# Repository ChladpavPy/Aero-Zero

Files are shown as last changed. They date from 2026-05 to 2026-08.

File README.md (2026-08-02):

# Aero-Zero Custom Flight Controller

I started this project, because I wanted to build fully autonomous ai drone. When I looked at the flight controllers available on the market, they were full of hardware that I just do not need or just that I could not add things that I want (for example the Rasberry pi zero 2w) . Most boards also waste a lot of space on powering analog OSD chips, which is completely useless for me because I am flying a purely digital HD system like Walksnail Avatar. Because the technology changed and digital is the standard now, I realized it is just a waste of space to keep the analog stuff and massive connectors.

I am using Raspberry Pi Zero 2W as the computer. Firstly I wanted to use something more powerful to be able to run ai smoother, like allwinner cubie a7z, but it is more expensive and the biggest issue is the firmware and gpio programming on this device. I have no idea, how I would programm this device, when there are basically no manuals or datasheets to this, so I am using the basic raspberry pi zero 2w. So the most interesting thing on this pcb is the pi zero 2w, which is connected to the board by set of pins and screw holes that can be mounted on the pcb by screws.

The drone itself would be able to lift off and fly to a location based on the gps, there is the barometer, from which the drone gets the current altitude and can get to ground. I am using walksnail camera and elrs, plus LIDAR. There is a jst connector for led strip, while at the same time there are built in leds on the drone chassis, esc unit connector and built in electromagnetic buzzer and boot and rst buttons.

The first stage was actually studying the STM32 pinouts and figuring out as much possible of how modern flight controllers handle gyro SPI communication and high speed SDIO routing.

A custom mainboard designed to replace standard generic flight controllers. Built to handle Betaflight high speed kinematics and communicate directly with a Raspberry Pi Zero 2W. Designed entirely from scratch in KiCad 10.

## Project Features

* **Microcontroller:** STM32F405 (100-pin, 32-bit ARM Cortex-M4)
* **Stackup:** 4-Layer PCB (Signal / GND / GND+Power / Signal) for internal routing and better EMI shielding against switching inductors
* **IMU (Gyro):** TDK InvenSense ICM-42688-P connected via dedicated hardware SPI1 bus for high-speed kinematics
* **Barometer:** Goertek SPL06-007 on-board sensor for accurate altitude telemetry
* **Power:** VBAT main input with robust 5V switching regulator (TPS54302) and isolated 3.3V sensor rails
* **Connectivity:** USB-C for main communication with USBLC6 ESD protection, native Raspberry Pi UART interface
* **Digital Video:** Dedicated Walksnail/Caddx VTX JST-SH port (Analog OSD intentionally removed to save space)
* **Storage:** Integrated MicroSD slot (Hirose Push-Pull) routed via high-speed 4-bit SDIO bus for blackbox logging
* **Hardware Protections:** Strict 1:1 hardware pin layout for GPS and LiDAR connectors to prevent accidental voltage shorts during assembly
* **Radio Link:** Dedicated UART port for 2.4GHz ExpressLRS nano receiver.

## Firmware

Since this board is built around a custom STM32F405 microcontroller, it runs on the open-source [Betaflight](https://github.com/betaflight/betaflight) firmware. Instead of writing custom flight control loops from scratch, the firmware setup uses a custom target configuration. You can find the complete pin-mapping and resource file (`AeroZero_BF_Config.txt`) ready in the `Firmware` folder.

## Gallery

### 3D PCB Render
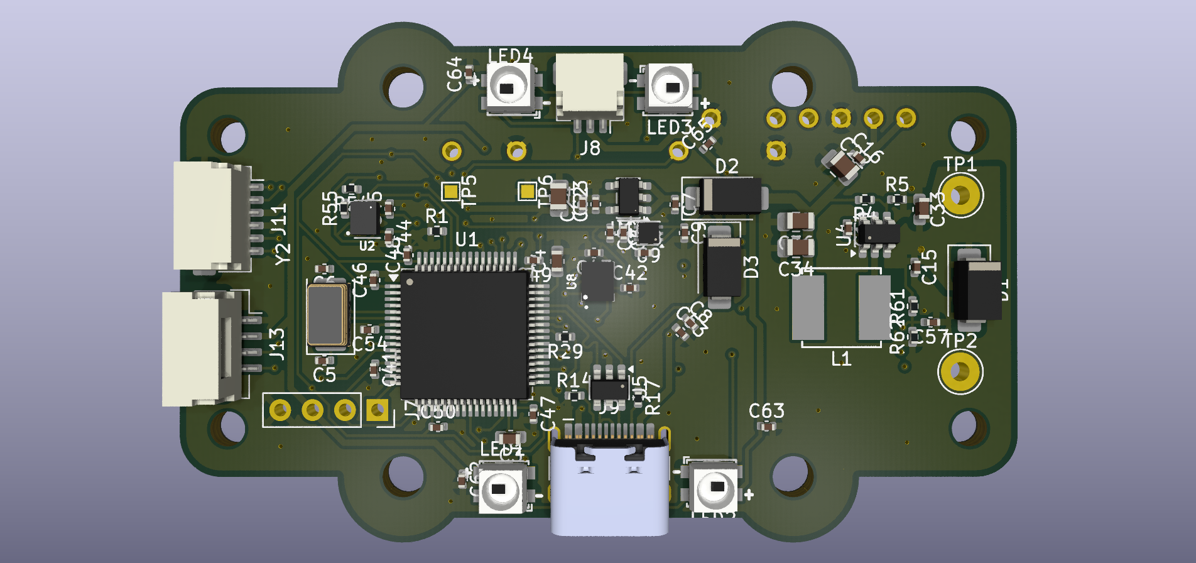
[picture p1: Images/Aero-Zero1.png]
PCB 3D Top


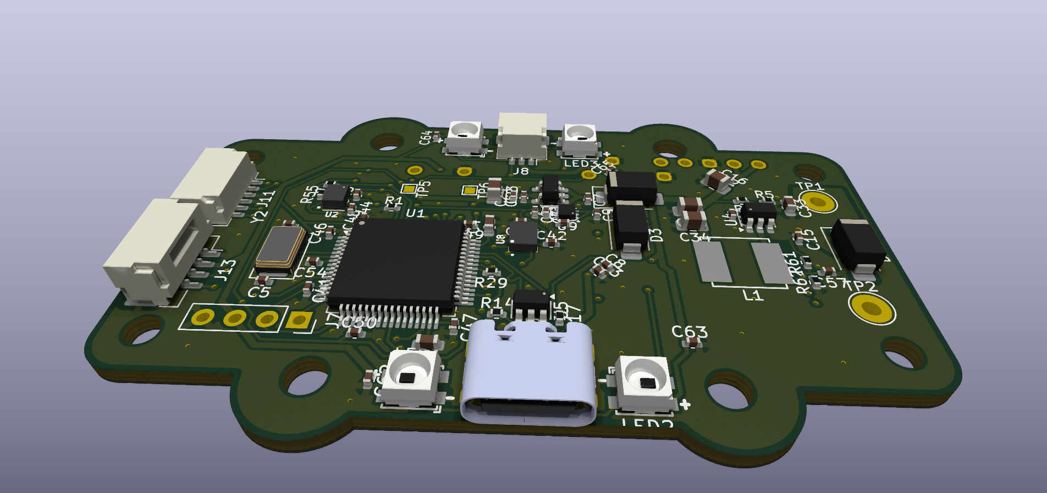
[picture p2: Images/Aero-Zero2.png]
PCB 3D Angle


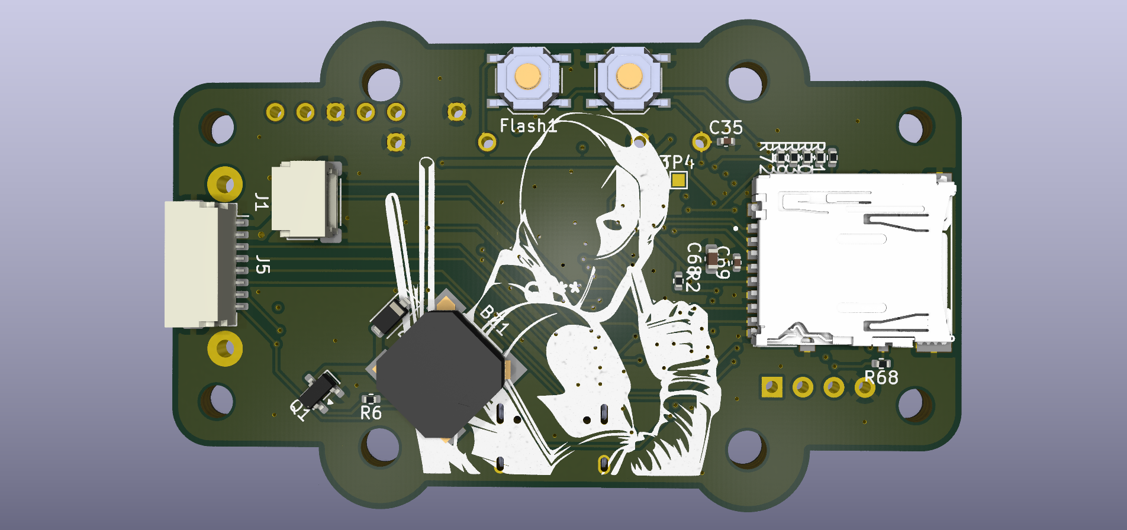
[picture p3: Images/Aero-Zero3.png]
PCB 3D Bottom


### PCB 

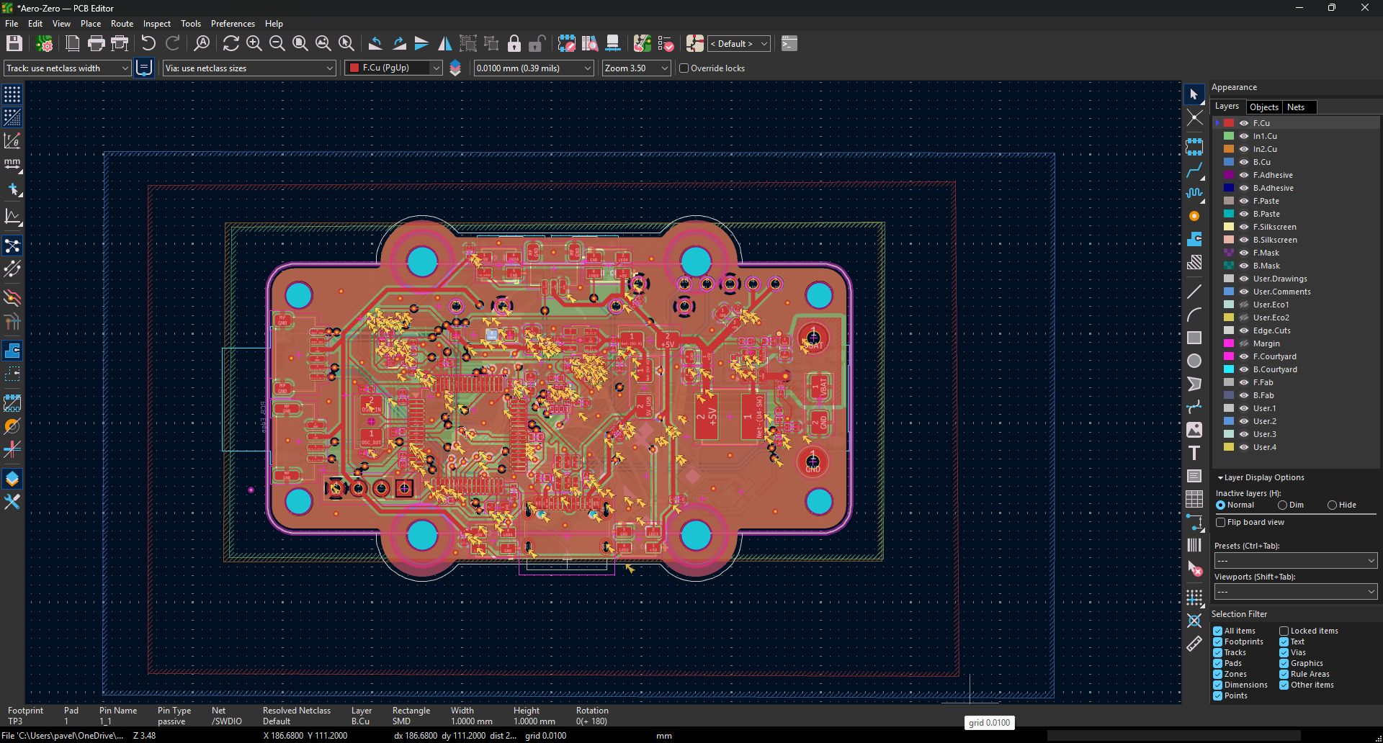
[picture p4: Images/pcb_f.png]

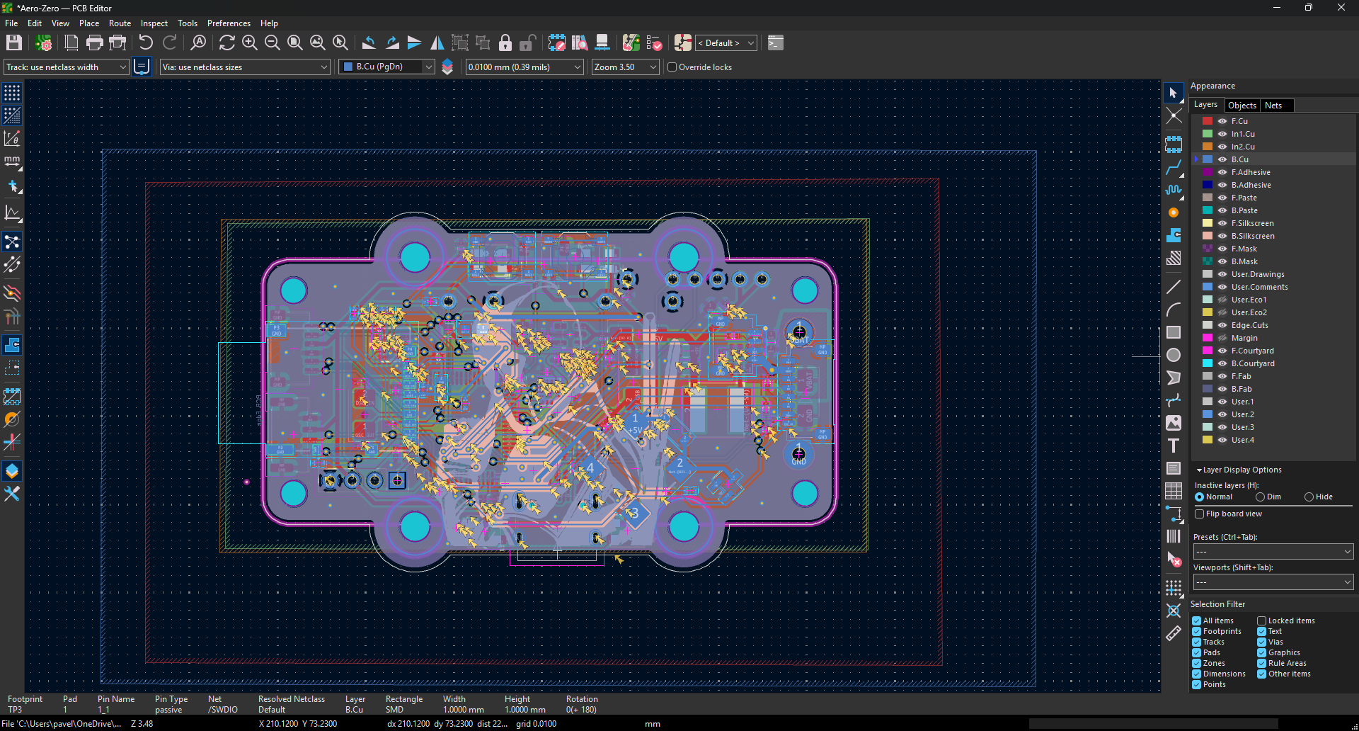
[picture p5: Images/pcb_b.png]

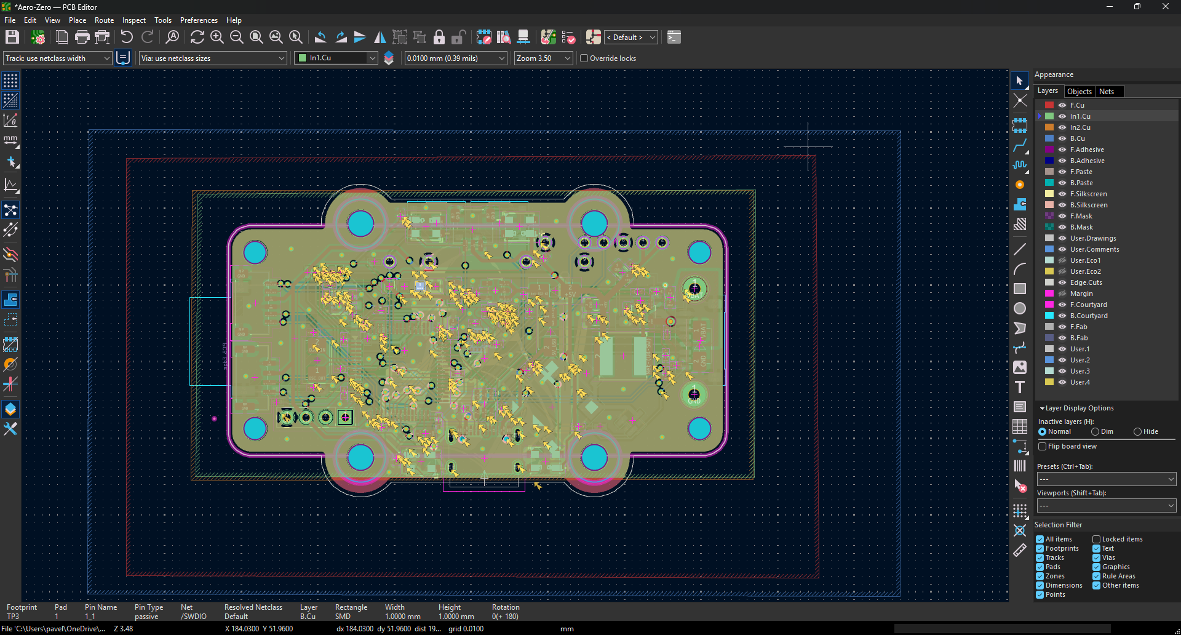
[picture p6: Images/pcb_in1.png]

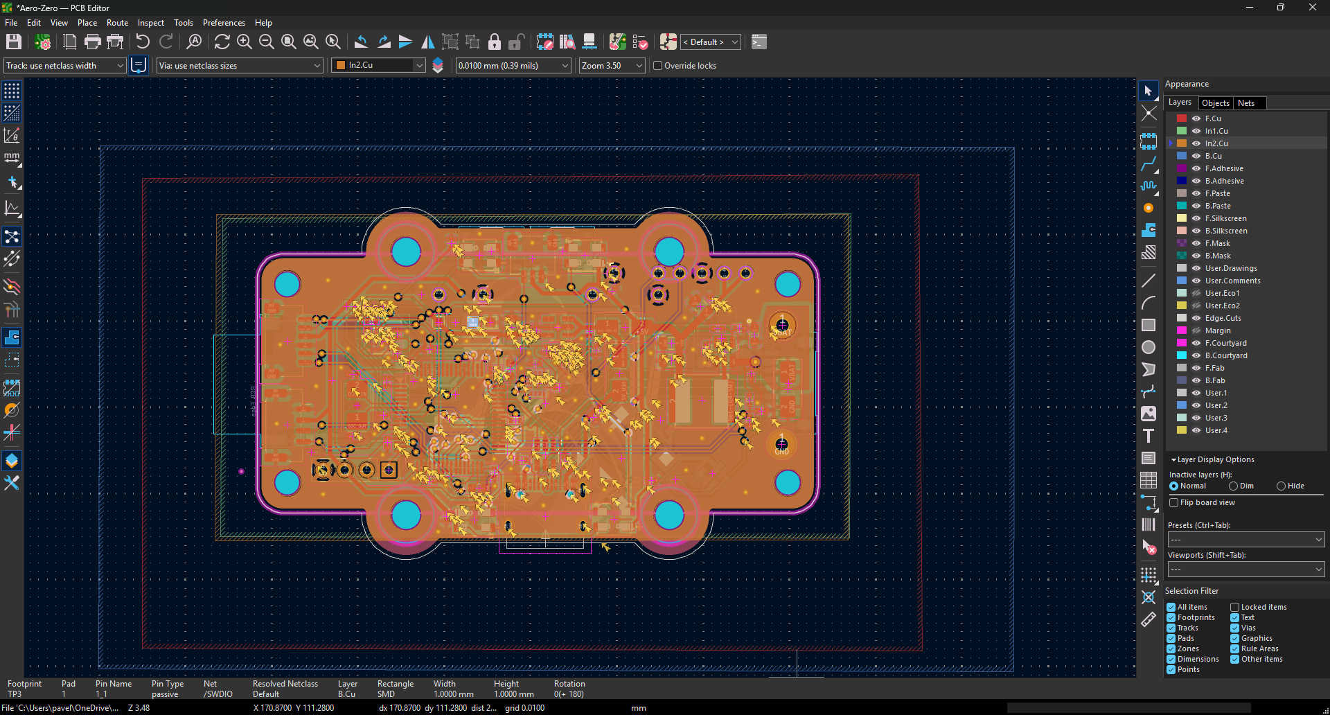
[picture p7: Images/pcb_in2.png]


### Schematics

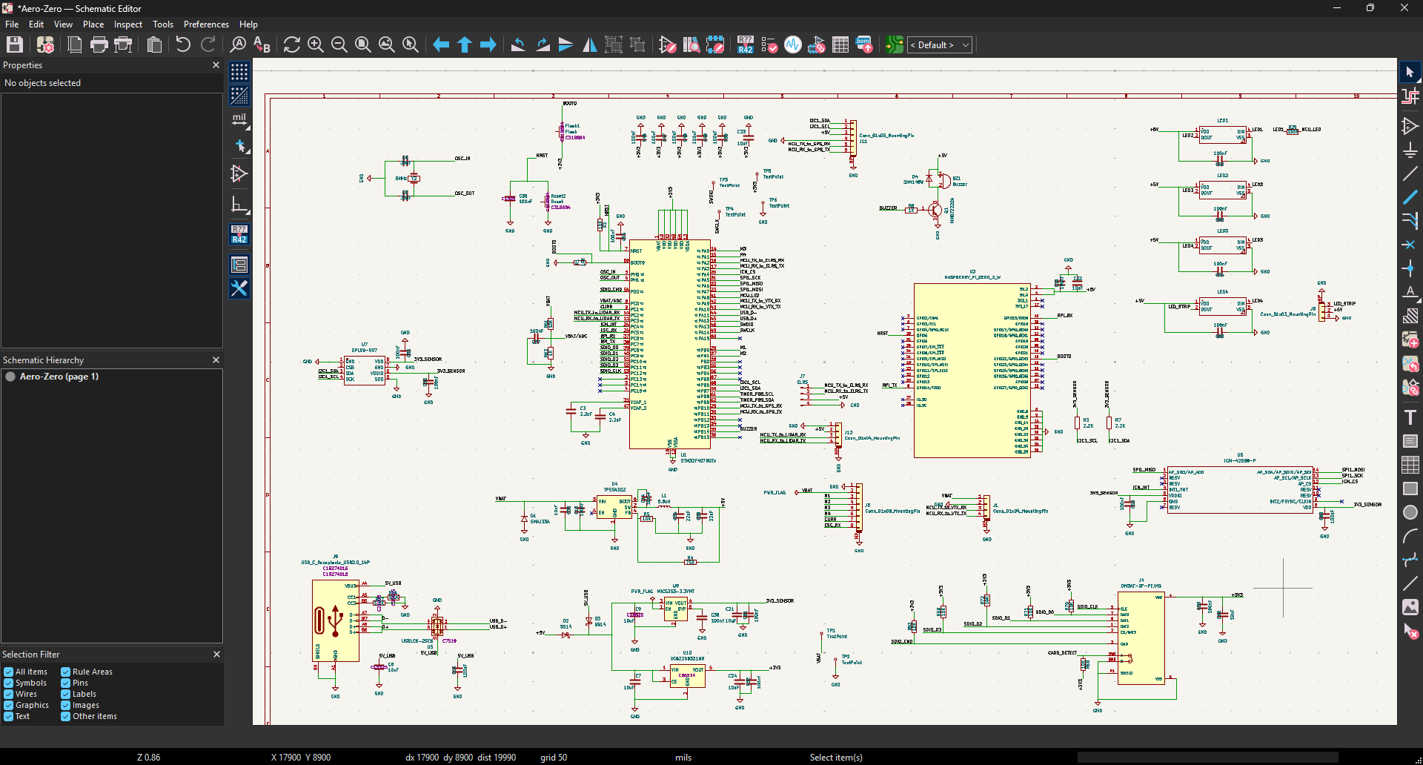
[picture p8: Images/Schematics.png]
SCHEMATICS


### Mechanical Integration MARK4
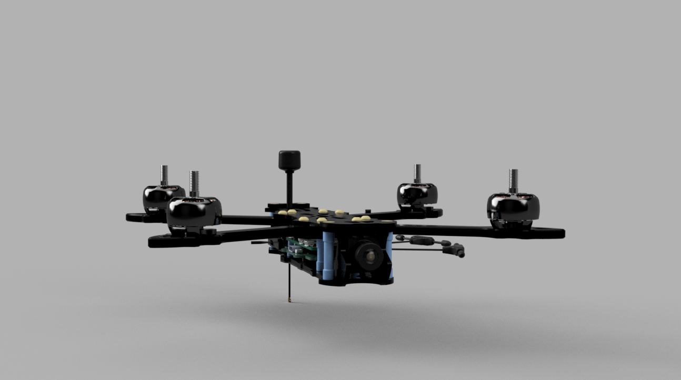
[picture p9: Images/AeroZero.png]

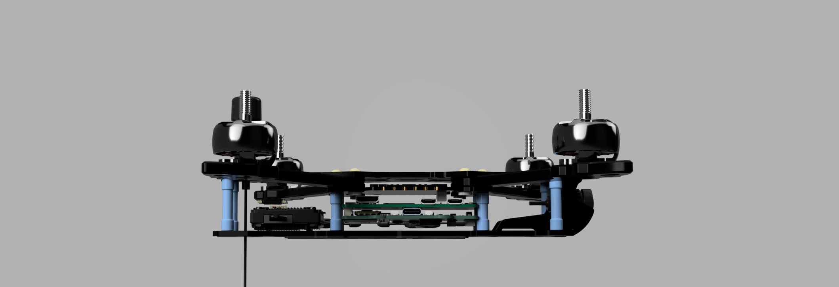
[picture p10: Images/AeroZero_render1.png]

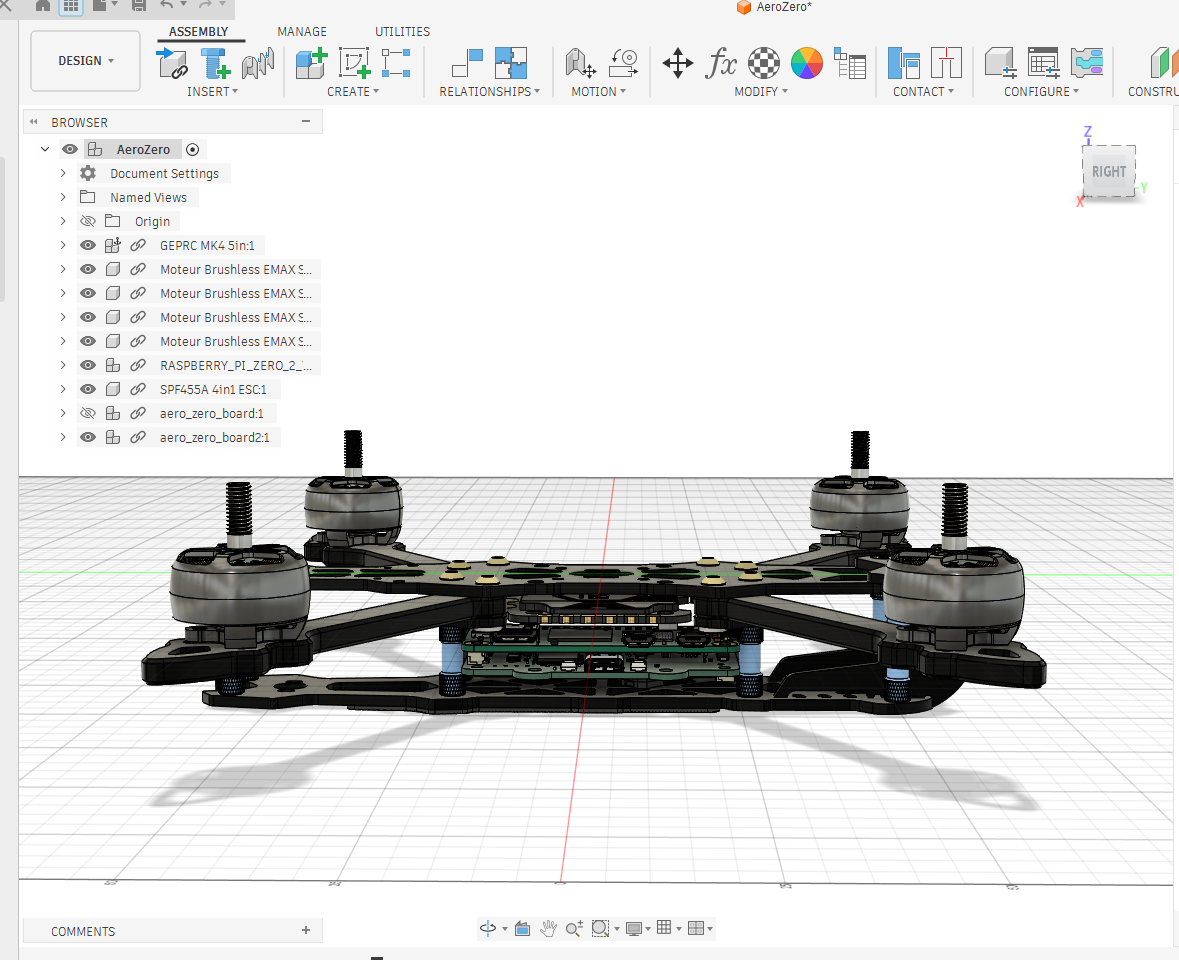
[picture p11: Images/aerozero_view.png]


### Mechanical Integration CUSTOM AERO-ZERO CAD
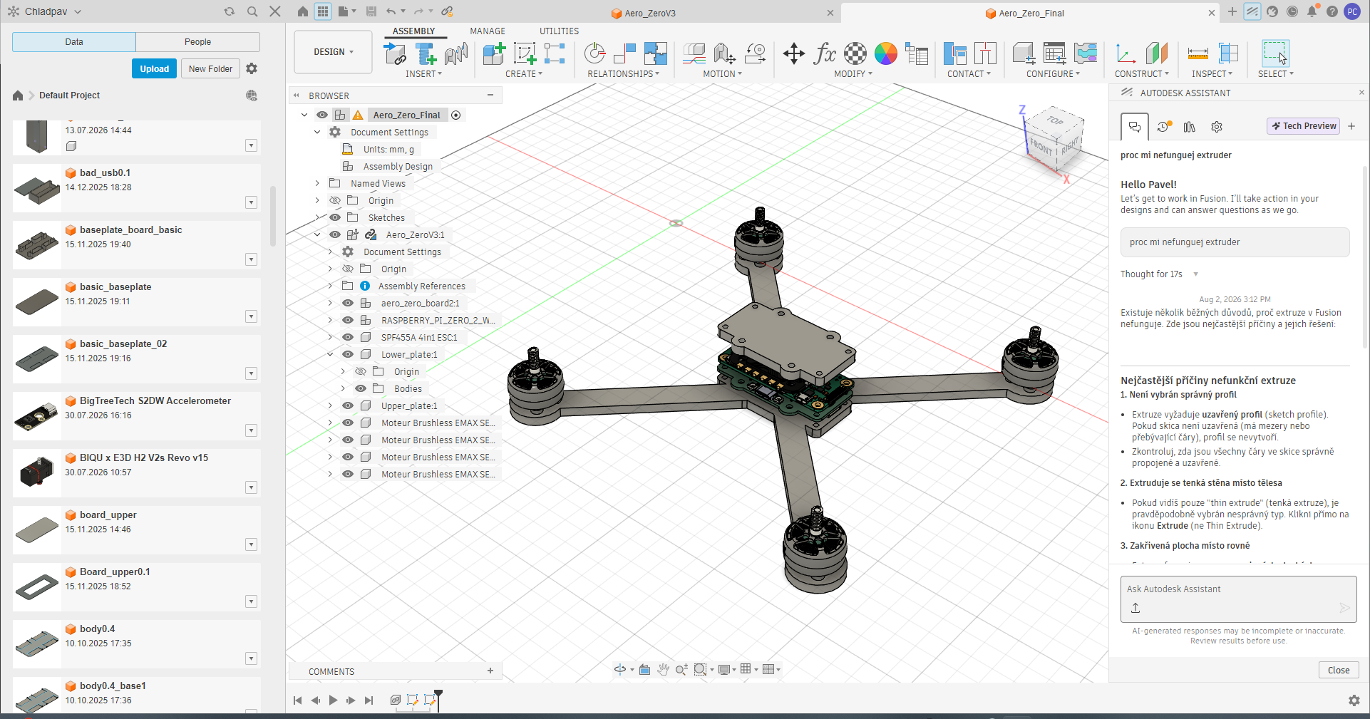
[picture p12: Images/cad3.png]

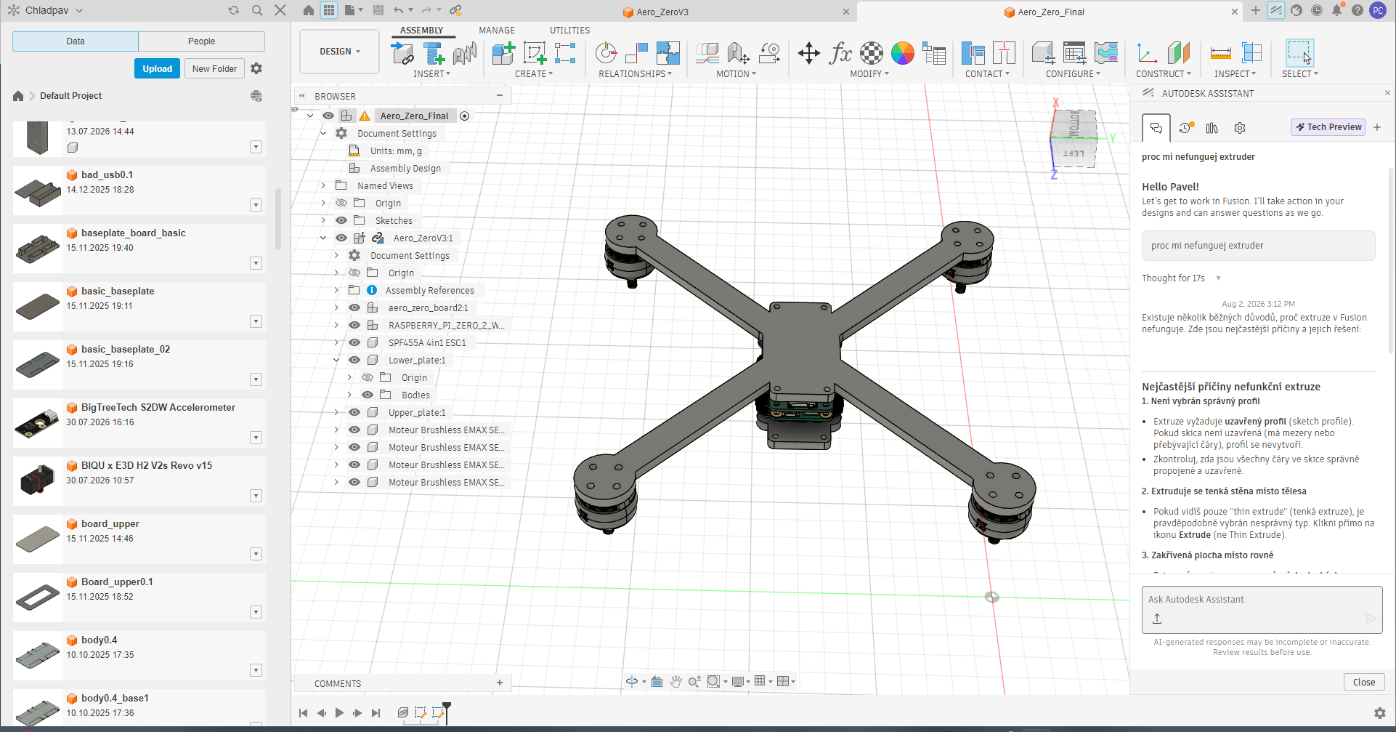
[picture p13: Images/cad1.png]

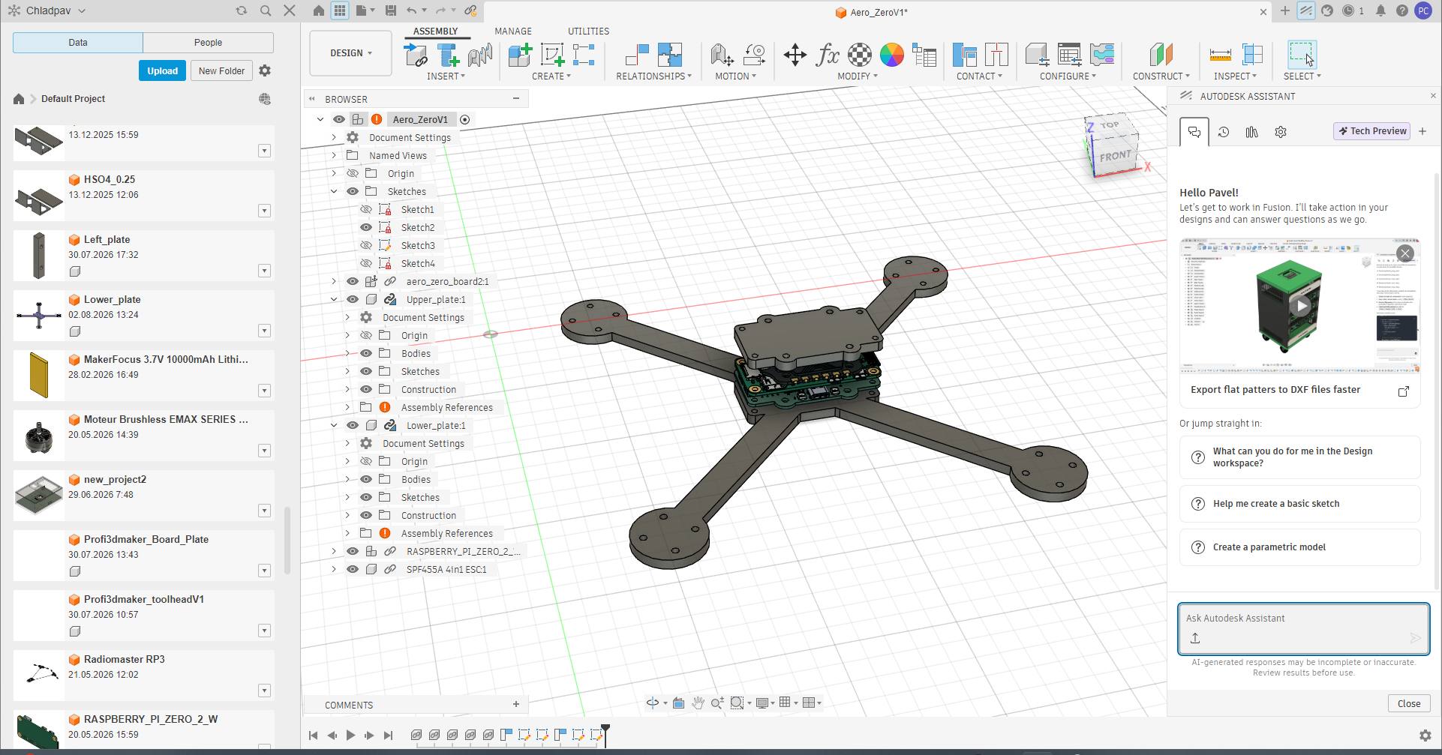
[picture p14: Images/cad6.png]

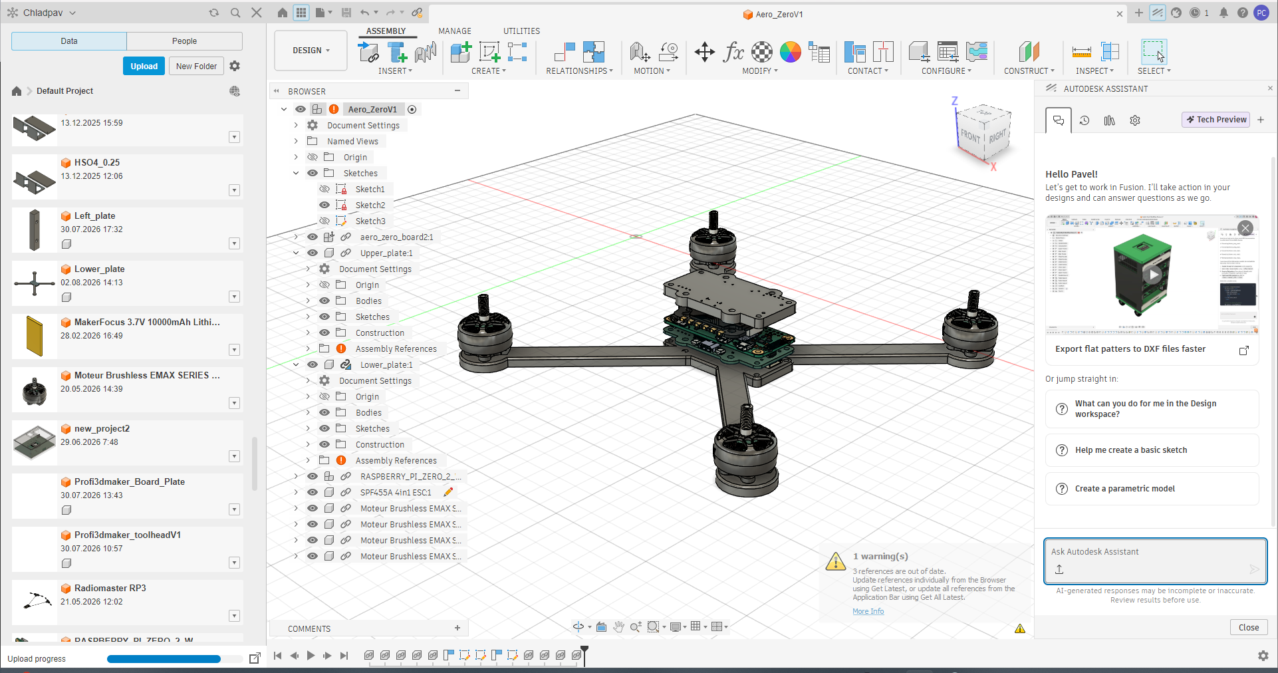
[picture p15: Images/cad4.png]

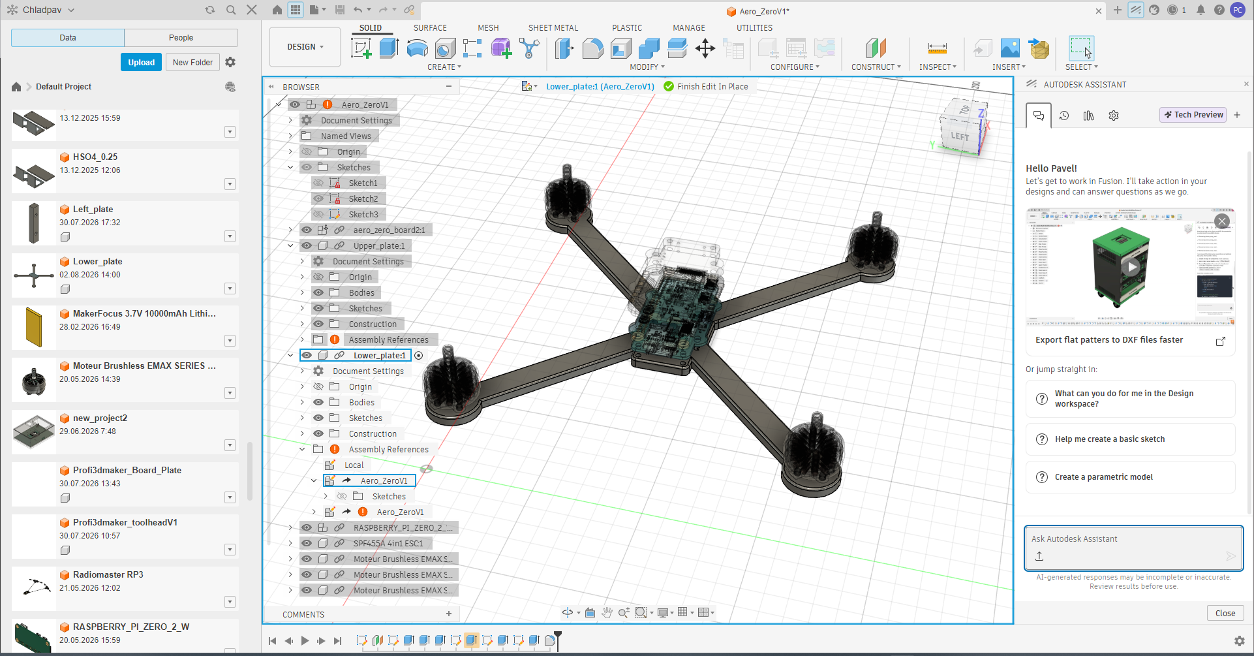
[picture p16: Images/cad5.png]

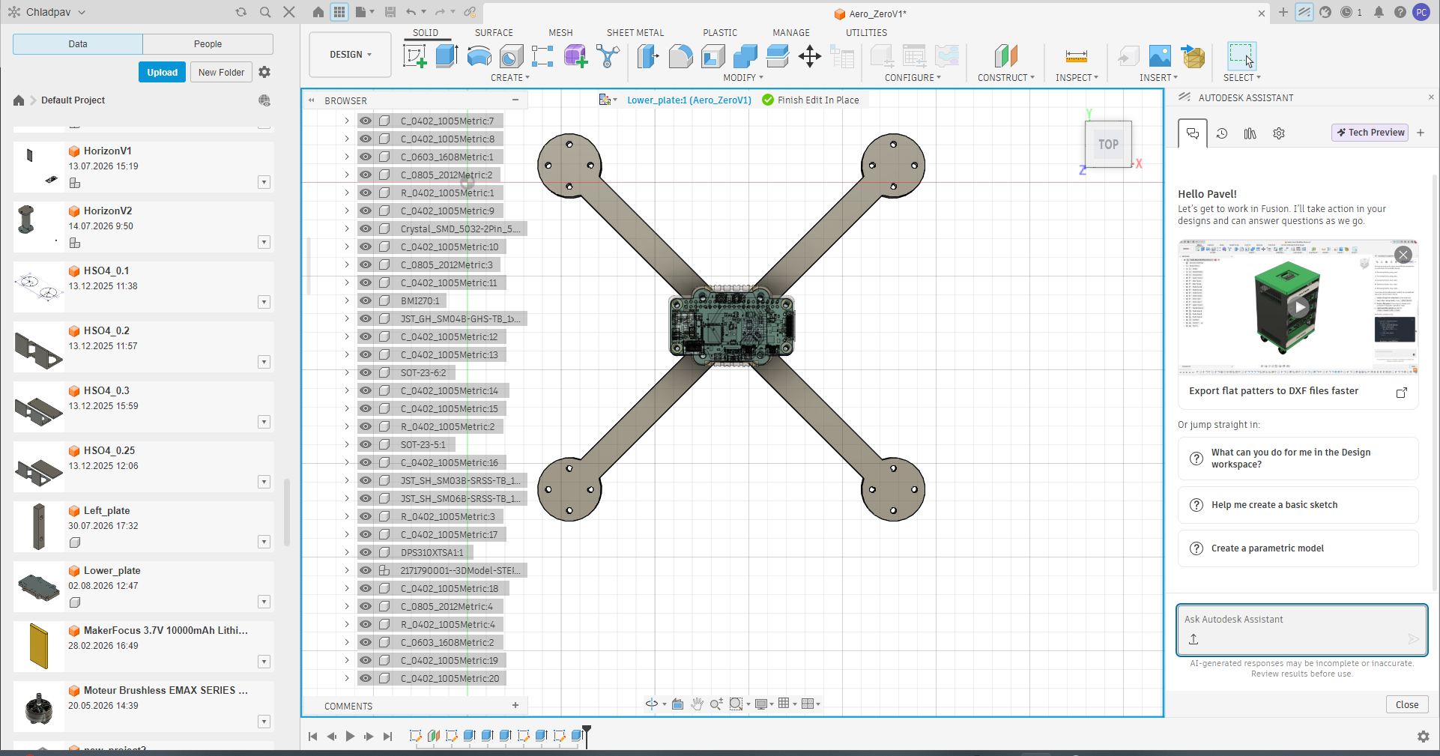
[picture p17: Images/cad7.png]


---

## Bill of Materials (BOM)

| Component | Qty | Purpose / Description | Price (USD) | Link / Distributor |
| :--- | :---: | :--- | :--- | :--- |
| **Custom PCBA (Aero-Zero)** | 2 | Custom designed 4-layer STM32 flight controller board. Fully assembled via JLCPCB SMT. | $131.50 | JLCPCB |
| **GEPRC GEP-M1025-DQ GPS** | 1 | High-precision positioning data (u-blox M10) with integrated QMC5883L compass and backup DPS310 barometer. | $19.80 | [Banggood](https://www.banggood.com/cs/GEPRC-GEP-M1025-Series-M10-Chip-GPS-Module-for-RC-Drone-FPV-Racing-Helicopter-Quadcopter-RC-Airplane-Car-p-2000868.html?ID=6324596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) |
| **SpeedyBee BLS 60A 30x30 4-in-1 ESC** | 1 | Electronic Speed Controller (4-in-1) for driving the primary flight motors | $44.00 | [AliExpress](https://www.aliexpress.com/item/1005010400734832.html) |
| **EMAX ECO II 2207 1700KV Brushless Motor** | 4 | Primary propulsion system providing lift and flight dynamics for the drone chassis | $59.00 | [AliExpress](https://www.aliexpress.com/item/1005001706267138.html) |
| **Raspberry Pi Zero 2 W** | 1 | Secondary AI and computer vision processing unit for autonomous flight capabilities | $20.17 | [RPiShop (Czech Republic)](https://rpishop.cz/raspberry-pi-zero/4311-raspberry-pi-zero-2-w.html) |
| **BETAFPV Nano 2.4GHz ELRS** | 1 | 2.4GHz ExpressLRS receiver with T-Type antenna for reliable, low-latency radio control link. | $9.07 | [Aliexpress](https://a.aliexpress.com/_EHLASWw) |
| **LCSC Discrete Components** | 1 | Bottom-side passive components (SD slot, buzzer, flyback diode, resistors/capacitors) for manual assembly. | $16.21 | lcsc.com |

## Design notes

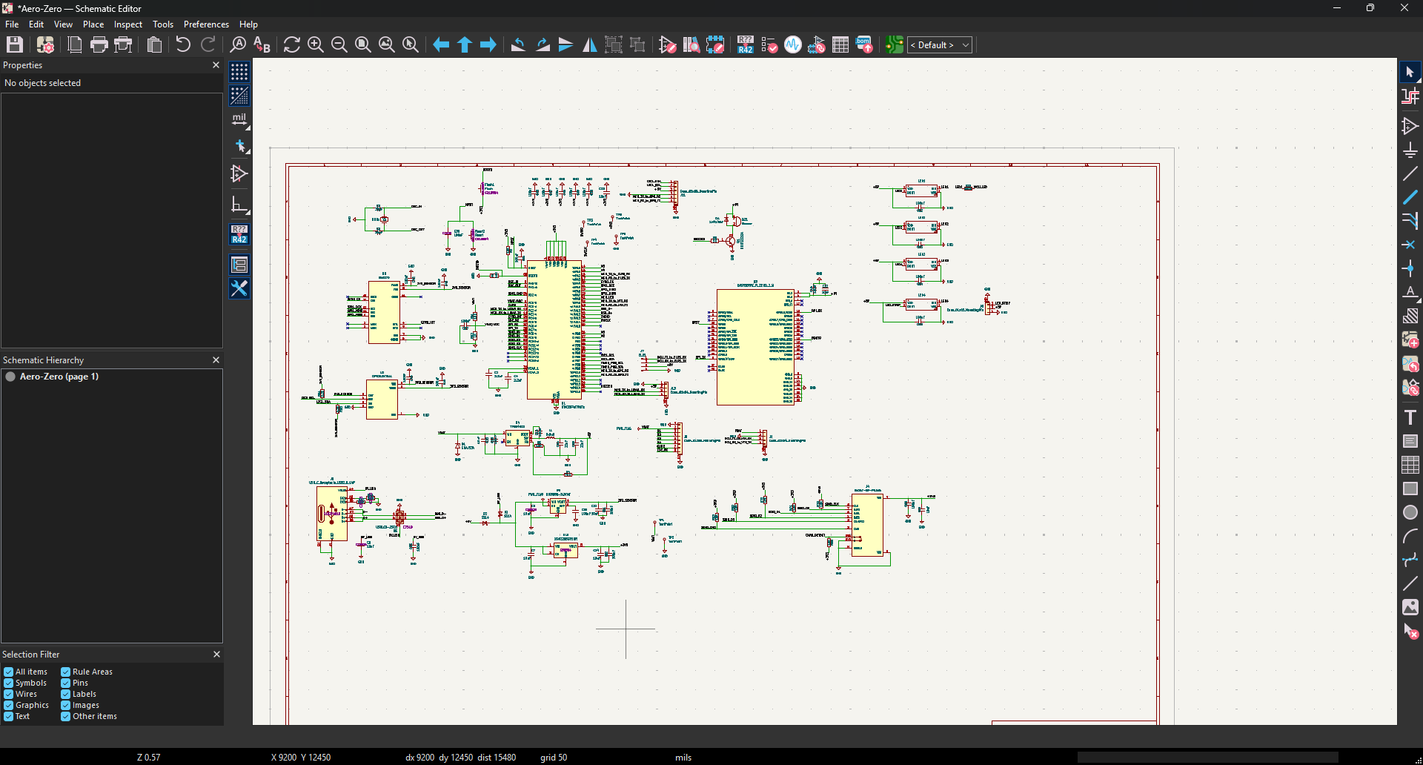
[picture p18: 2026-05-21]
Images/schematics2.png

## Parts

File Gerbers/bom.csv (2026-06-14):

Designator | Footprint | Quantity | Value | LCSC Part #
BZ1 | BUZ-SMD_4P-L8.5-W8.5-P8.50-TL | 1 | Buzzer | C95298
C14, C15, C16, C38, C41, C46, C47, C48, C49, C50, C51, C52, C53, C54, C55, C56, C57, C58, C60, C62, C63, C64, C65, C69 | 0402 | 24 | 100nF | C307331
C21, C24, C7 | 0402 | 3 | 10uF | C15850
C22, C23 | 0805 | 2 | 10uF | C15850
C3, C4 | 0603 | 2 | 2.2uF | C23630
C33, C68 | 0603 | 2 | 10uF | C19702
C34, C36 | 0805 | 2 | 22uF | C45783
C35 | 0402 | 1 | 100nF | C1525
C5, C6 | 0402 | 2 | 33pF | C1562
C8, C9 | 0402 | 2 | 10uF | C15525
D1 | D_SMA | 1 | SMAJ33A | C113966
D2, D3 | D_SMA | 2 | SS14 | C2480
D4 | D_SOD-123 | 1 | 1N4148W | C81598
FLASH1 | SW_Push_1P1T_XKB_TS-1187A | 1 | Flash | C318884
J1 | JST_SH_SM04B-SRSS-TB_1x04-1MP_P1.00mm_Horizontal | 1 | Conn_01x04_MountingPin
J11 | JST_SH_SM06B-SRSS-TB_1x06-1MP_P1.00mm_Horizontal | 1 | Conn_01x06_MountingPin
J13 | JST_GH_SM04B-GHS-TB_1x04-1MP_P1.25mm_Horizontal | 1 | Conn_01x04_MountingPin
J4 | HRS_DM3AT-SF-PEJM5_card | 1 | DM3AT-SF-PEJM5 | C114218
J5 | JST_SH_SM08B-SRSS-TB_1x08-1MP_P1.00mm_Horizontal | 1 | Conn_01x08_MountingPin
J7 | PinSocket_1x04_P2.54mm_Vertical | 1 | ELRS
J8 | JST_SH_SM03B-SRSS-TB_1x03-1MP_P1.00mm_Horizontal | 1 | Conn_01x03_MountingPin
J9 | USB_C_Receptacle_HCTL_HC-TYPE-C-16P-01A | 1 | USB_C_Receptacle_USB2.0_14P | C19274016
L1 | IND-SMD_L6.0-W6.0_SWPA6045S | 1 | 6.8uH | C57254
LED1, LED2, LED3, LED4 | LED-SMD_4P-L3.5-W3.5-TL_WS2812B | 4 | ~ | C527089
Q1 | SOT-23 | 1 | MMBT2222A | C8512
R1, R2, R5, R53, R61, R68, R69, R70, R71, R72 | 0402 | 10 | 10K | C25804
R14, R17 | 0402 | 2 | 5.1K | C25905
R29 | 0402 | 1 | 330R | C25104
R3, R7 | 0402 | 2 | 2.2K | C25879
R4 | 0603 | 1 | 75K | C23242
R54, R55 | 0402 | 2 | 2,2K | C25879
R6, R62 | 0402 | 2 | 1K | C11702
RESET2 | SW_Push_1P1T_XKB_TS-1187A | 1 | Reset | C318884
TP1, TP2 | TestPoint_THTPad_D3.0mm_Drill1.5mm | 2 | TestPoint
TP3, TP4, TP5, TP6 | TestPoint_Pad_1.0x1.0mm | 4 | TestPoint
U1 | LQFP-64_10x10mm_P0.5mm | 1 | STM32F407RGTx | C15742
U10 | SOT-23-5 | 1 | XC6220B331MR | C86534
U3 | RpiZero2W_Redukce_Final | 1 | RASPBERRY_PI_ZERO_2_W
U4 | SOT-23-6 | 1 | TPS54302 | C311983
U5 | SOT-23-6 | 1 | USBLC6-2SC6 | C7519
U6 | LGA-14_L3.0-W2.5-P0.50-TL | 1 | ICM-42688-P | C1850418
U7 | SENSOR-SMD_SPL06-007 | 1 | SPL06-007 | C233787
U9 | MLF-6-1EP_1.6x1.6mm_P0.5mm_EP0.5x1.26mm | 1 | MIC5353-3.3YMT | C511311
Y2 | Crystal_SMD_5032-2Pin_5.0x3.2mm | 1 | 8MHz | C115962

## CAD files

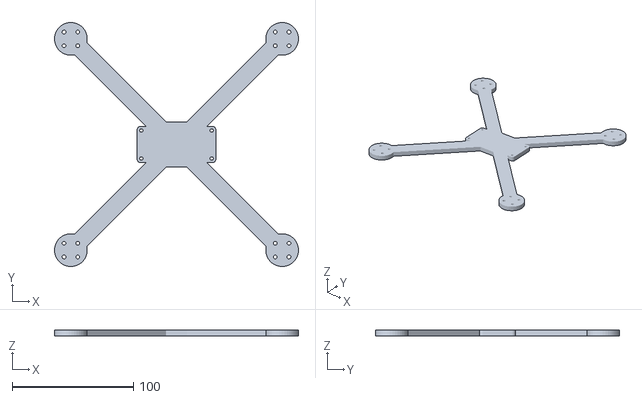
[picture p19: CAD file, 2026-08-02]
3D_Models/Lower_plate.stl
200.9 x 200.9 x 5.00

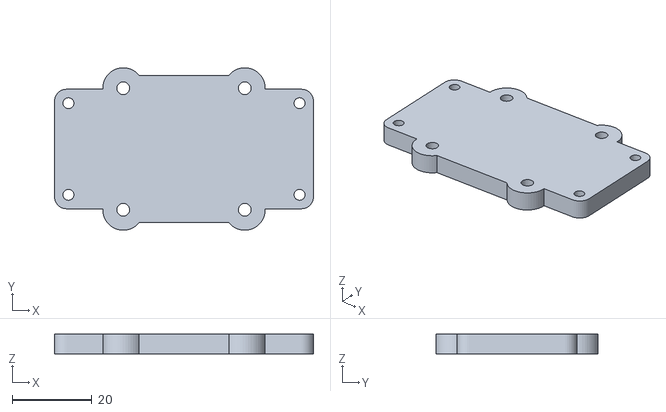
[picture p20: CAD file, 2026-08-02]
3D_Models/Upper_plate.stl
65.0 x 40.8 x 5.00

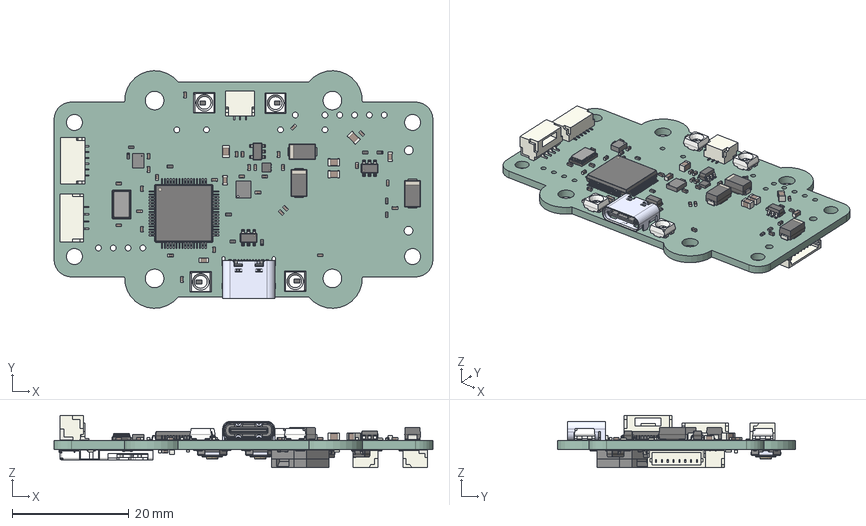
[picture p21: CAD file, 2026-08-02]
3D_Models/aero_zero_board2.step
65.0 x 40.8 x 8.93 mm
C_0402_1005Metric x 32
SOT-23-6 x 2
C_0805_2012Metric x 4
SMD WS2812B Mini x 4
C_0603_1608Metric x 4
R_0402_1005Metric x 18
Crystal_SMD_5032-2Pin_5.0x3.2mm
BMI270
JST_GH_SM04B-GHS-TB_1x04-1MP_P1.25mm_Horizontal
SOT-23-5
JST_SH_SM03B-SRSS-TB_1x03-1MP_P1.00mm_Horizontal
JST_SH_SM06B-SRSS-TB_1x06-1MP_P1.00mm_Horizontal
DPS310XTSA1
D_SMA x 3
MLF-6-1EP_1.6x1.6mm_P0.5mm_EP0.5x1.26mm
LQFP-64_10x10mm_P0.5mm
D_SOD-123
TS-1187A-B-A-B--3DModel-STEP-56544 x 2
JST_SH_SM04B-SRSS-TB_1x04-1MP_P1.00mm_Horizontal
JST_SH_SM08B-SRSS-TB_1x08-1MP_P1.00mm_Horizontal
SOT-23
MLT-8530--3DModel-STEP-269445
DM3AT-SF-PEJM5
Aero-Zero_PCB

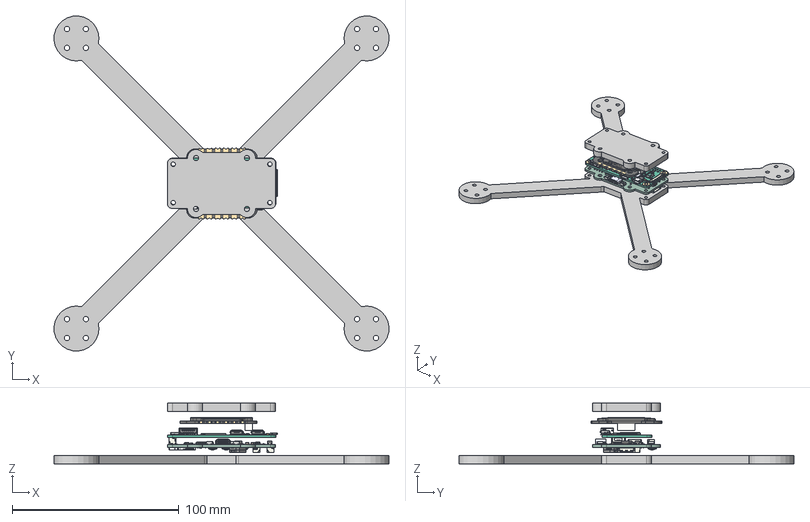
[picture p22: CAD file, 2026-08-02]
3D_Models/AeroZero_Final.step
200.9 x 200.9 x 36.5 mm

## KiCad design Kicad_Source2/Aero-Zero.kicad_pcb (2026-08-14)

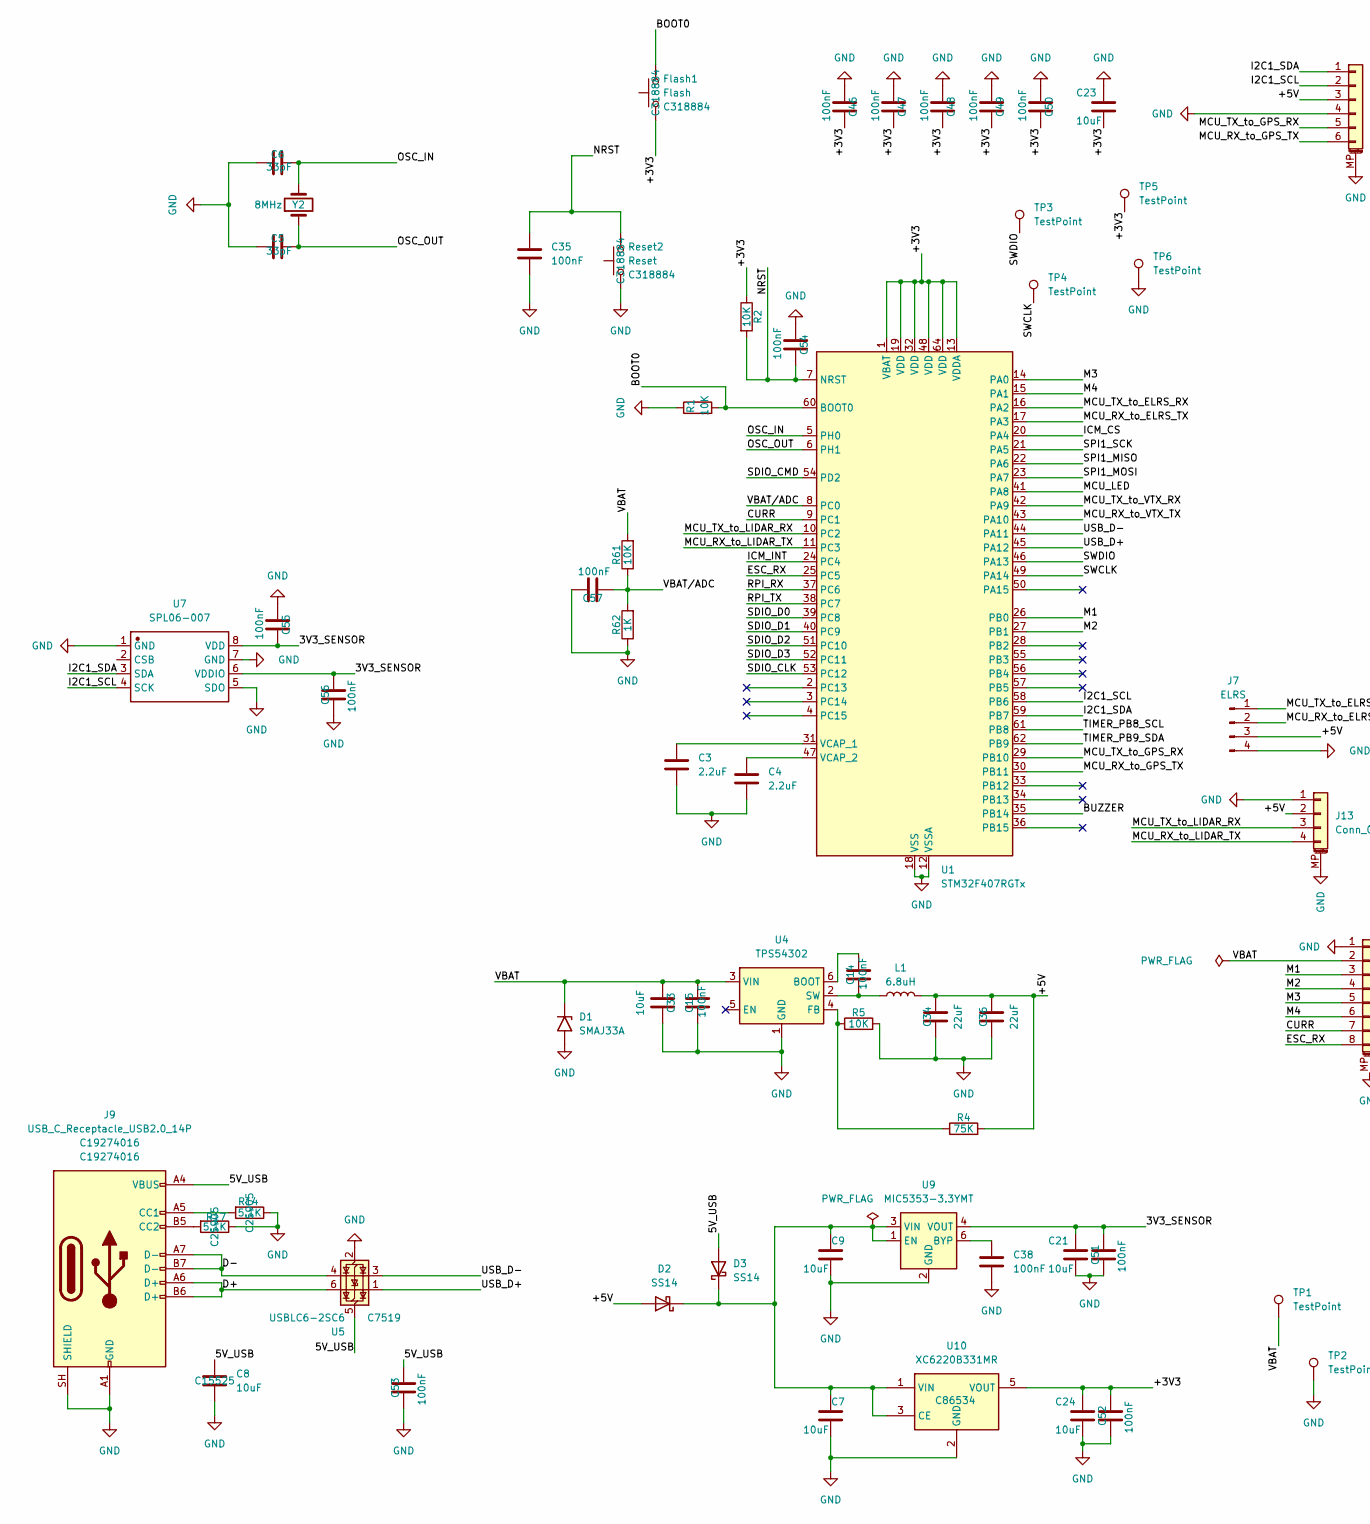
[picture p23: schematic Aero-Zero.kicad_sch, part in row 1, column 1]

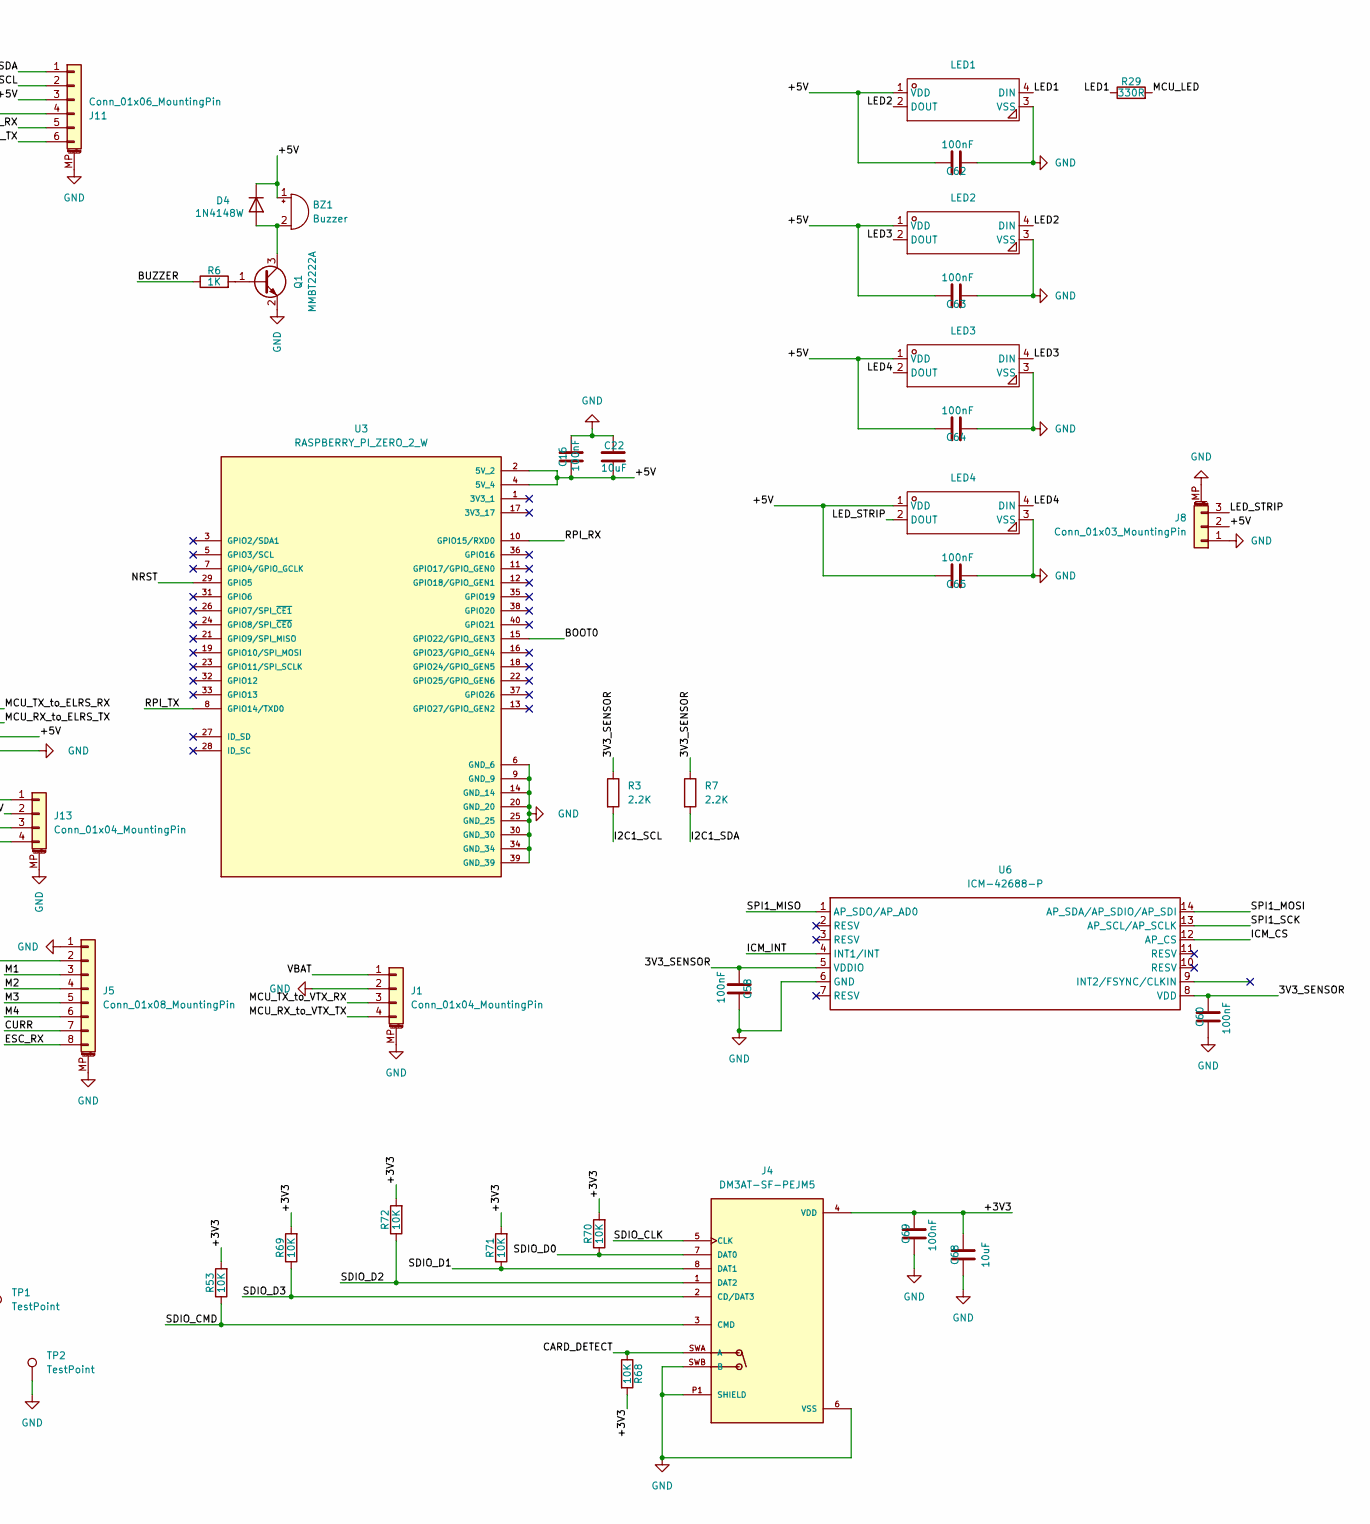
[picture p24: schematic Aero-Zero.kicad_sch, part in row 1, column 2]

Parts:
BZ1: Buzzer; BUZ-SMD_4P-L8.5-W8.5-TL; LCSC C556939
C3, C4: 2.2uF; C_0603_1608Metric; LCSC C23630
C5, C6: 33pF; C_0402_1005Metric; LCSC C1562
C7, C33, C68: 10uF; C_0603_1608Metric; LCSC C19702
C8: 10uF; C_0402_1005Metric; LCSC C15525
C9: 10uF; C_0603_1608Metric; MNF PART NUMBER C15525; LCSC C19702
C14, C15, C16, C46, C47, C48, C49, C50, C51, C52, C53, C54, C55, C56, C57, C58, C60, C62, C63, C64, C65: 100nF; C_0402_1005Metric; LCSC C307331
C21, C24: 10uF; C_0402_1005Metric; MNF PART NUMBER C15525; LCSC C15525
C22, C23: 10uF; C_0805_2012Metric; MNF PART NUMBER C15850; LCSC C15850
C34, C36: 22uF; C_0805_2012Metric; LCSC C45783
C35: 100nF; C_0603_1608Metric; MNF PART NUMBER C14663; LCSC C14663
C38: 100nF; C_0402_1005Metric; MNF PART NUMBER C307331; LCSC C307331
C69: 100nF; C_0603_1608Metric; LCSC C14663
D1: SMAJ33A; D_SMA; LCSC C113966
D2, D3: SS14; D_SMA; LCSC C2480
D4: 1N4148W; D_SOD-123; LCSC C81598
Flash1: Flash; SW_Push_1P1T_XKB_TS-1187A; MNF PART NUMBER C318884; LCSC C318884
J1: Conn_01x04_MountingPin; JST_SH_SM04B-SRSS-TB_1x04-1MP_P1.00mm_Horizontal
J4: DM3AT-SF-PEJM5; HRS_DM3AT-SF-PEJM5_card; PARTREV 20200913; DigiKey_Part_Number HR1964CT-ND
J5: Conn_01x08_MountingPin; JST_SH_SM08B-SRSS-TB_1x08-1MP_P1.00mm_Horizontal
J7: ELRS; PinSocket_1x04_P2.54mm_Vertical
J8: Conn_01x03_MountingPin; JST_SH_SM03B-SRSS-TB_1x03-1MP_P1.00mm_Horizontal
J9: USB_C_Receptacle_USB2.0_14P; USB_C_Receptacle_HCTL_HC-TYPE-C-16P-01A; MNF PART NUMBER C19274016; LCSC C19274016
J11: Conn_01x06_MountingPin; JST_SH_SM06B-SRSS-TB_1x06-1MP_P1.00mm_Horizontal
J13: Conn_01x04_MountingPin; JST_GH_SM04B-GHS-TB_1x04-1MP_P1.25mm_Horizontal
L1: 6.8uH; IND-SMD_L6.0-W6.0_SWPA6045S; LCSC C57254
LED1, LED2, LED3, LED4: LED-SMD_4P-L3.5-W3.5-TL_WS2812B; Manufacturer Part WS2812B-B/T; LCSC Part Name RGB三色
Q1: MMBT2222A; SOT-23; LCSC C8512
R1, R5, R61: 10K; R_0402_1005Metric; LCSC C25804
R2: 10K; C_0603_1608Metric; LCSC C25804
R3, R7: 2.2K; R_0402_1005Metric; LCSC C25879
R4: 75K; R_0603_1608Metric; LCSC C23242
R6: 1K; R_0603_1608Metric; LCSC C21190
R14, R17: 5.1K; R_0402_1005Metric; MNF PART NUMBER C25905; LCSC C25905
R29: 330R; R_0402_1005Metric; LCSC C25104
R53, R68, R69, R70, R71, R72: 10K; R_0603_1608Metric; LCSC C25804
R62: 1K; R_0402_1005Metric; LCSC C11702
Reset2: Reset; SW_Push_1P1T_XKB_TS-1187A; MNF PART NUMBER C318884; LCSC C318884
TP1, TP2: TestPoint; TestPoint_THTPad_D3.0mm_Drill1.5mm
TP3, TP4, TP5, TP6: TestPoint; TestPoint_Pad_1.0x1.0mm
U1: STM32F407RGTx; LQFP-64_10x10mm_P0.5mm; LCSC C15742
U3: RASPBERRY_PI_ZERO_2_W; RpiZero2W_Redukce_Final; PARTREV April 2024
U4: TPS54302; SOT-23-6; LCSC C311983
U5: USBLC6-2SC6; SOT-23-6; MNF PART NUMBER C7519; LCSC C7519
U6: ICM-42688-P; LGA-14_L3.0-W2.5-P0.50-TL; Manufacturer Part ICM-42688-P; LCSC C1850418
U7: SPL06-007; SENSOR-SMD_SPL06-007; Manufacturer Part SPL06-007; LCSC C233787
U9: MIC5353-3.3YMT; MLF-6-1EP_1.6x1.6mm_P0.5mm_EP0.5x1.26mm; LCSC C511311
U10: XC6220B331MR; SOT-23-5; MNF PART NUMBER C86534; LCSC C86534
Y2: 8MHz; Crystal_SMD_5032-2Pin_5.0x3.2mm; LCSC C115962

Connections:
/3V3_SENSOR: C21.1, C51.1, C55.1, C56.1, C58.2, C60.1, R3.1, R7.1, U6.5 (VDDIO), U6.8 (VDD), U7.6 (VDDIO), U7.8 (VDD), U9.4 (VOUT); also elsewhere on the board
/5V_USB: C8.1, C53.1, D3.2 (A), J9.A4 (VBUS), J9.A9 (VBUS), J9.B4 (VBUS), J9.B9 (VBUS), U5.5 (VBUS)
/+3V3: C23.2, C24.1, C46.1, C47.1, C48.1, C49.1, C50.1, C52.1, C68.1, C69.1, Flash1.1, J4.4 (VDD), R2.1, R53.2, R68.2, R69.2, R70.2, R71.2, R72.2, TP5.1 (1_1), U1.1 (VBAT), U1.13 (VDDA), U1.19 (VDD), U1.32 (VDD), U1.48 (VDD), U1.64 (VDD), U10.5 (VOUT); also elsewhere on the board
/+5V: BZ1.1 (+), C16.2, C22.2, C34.1, C36.1, C62.1, C63.1, C64.1, C65.1, D2.2 (A), D4.1 (K), J7.3, J8.2, J11.3, J13.2, L1.2, LED1.1 (VDD), LED2.1 (VDD), LED3.1 (VDD), LED4.1 (VDD), R4.2, U3.2 (5V_2), U3.4 (5V_4)
/BOOT0: Flash1.2, R1.2, U1.60 (BOOT0), U3.15 (GPIO22/GPIO_GEN3)
/BUZZER: R6.1, U1.35 (PB14)
/CARD_DETECT: J4.SWA (A), R68.1
/CURR: J5.7, U1.9 (PC1)
/D+: J9.A6 (D+), J9.B6 (D+), U5.6 (I/O1)
/D-: J9.A7 (D-), J9.B7 (D-), U5.4 (I/O2)
/ESC_RX: J5.8, U1.25 (PC5)
/I2C1_SCL: J11.2, R3.2, U1.58 (PB6), U7.4 (SCK); also elsewhere on the board
/I2C1_SDA: J11.1, R7.2, U1.59 (PB7), U7.3 (SDA); also elsewhere on the board
/ICM_CS: U1.20 (PA4), U6.12 (AP_CS)
/ICM_INT: U1.24 (PC4), U6.4 (INT1/INT)
/LED1: LED1.4 (DIN), R29.1
/LED2: LED1.2 (DOUT), LED2.4 (DIN)
/LED3: LED2.2 (DOUT), LED3.4 (DIN)
/LED4: LED3.2 (DOUT), LED4.4 (DIN)
/LED_STRIP: J8.3, LED4.2 (DOUT)
/M1: J5.3, U1.26 (PB0)
/M2: J5.4, U1.27 (PB1)
/M3: J5.5, U1.14 (PA0)
/M4: J5.6, U1.15 (PA1)
/MCU_LED: R29.2, U1.41 (PA8)
/MCU_RX_to_ELRS_TX: J7.2, U1.17 (PA3)
/MCU_RX_to_GPS_TX: J11.6, U1.30 (PB11)
/MCU_RX_to_LIDAR_TX: J13.4, U1.11 (PC3)
/MCU_RX_to_VTX_TX: J1.4, U1.43 (PA10)
/MCU_TX_to_ELRS_RX: J7.1, U1.16 (PA2)
/MCU_TX_to_GPS_RX: J11.5, U1.29 (PB10)
/MCU_TX_to_LIDAR_RX: J13.3, U1.10 (PC2)
/MCU_TX_to_VTX_RX: J1.3, U1.42 (PA9)
/NRST: C35.1, C54.1, R2.2, Reset2.2, U1.7 (NRST), U3.29 (GPIO5)
/OSC_IN: C6.1, U1.5 (PH0), Y2.2
/OSC_OUT: C5.1, U1.6 (PH1), Y2.1
/RPI_RX: U1.37 (PC6), U3.10 (GPIO15/RXD0)
/RPI_TX: U1.38 (PC7), U3.8 (GPIO14/TXD0)
/SDIO_CLK: J4.5 (CLK), U1.53 (PC12)
/SDIO_CMD: J4.3 (CMD), R53.1, U1.54 (PD2)
/SDIO_D0: J4.7 (DAT0), R70.1, U1.39 (PC8)
/SDIO_D1: J4.8 (DAT1), R71.1, U1.40 (PC9)
/SDIO_D2: J4.1 (DAT2), R72.1, U1.51 (PC10)
/SDIO_D3: J4.2 (CD/DAT3), R69.1, U1.52 (PC11)
/SPI1_MISO: U1.22 (PA6), U6.1 (AP_SDO/AP_AD0)
/SPI1_MOSI: U1.23 (PA7), U6.14 (AP_SDA/AP_SDIO/AP_SDI)
/SPI1_SCK: U1.21 (PA5), U6.13 (AP_SCL/AP_SCLK)
/SWCLK: TP4.1 (1_1), U1.49 (PA14)
/SWDIO: TP3.1 (1_1), U1.46 (PA13)
/TIMER_PB8_SCL: U1.61 (PB8)
/TIMER_PB9_SDA: U1.62 (PB9)
/USB_D+: U1.45 (PA12), U5.1 (I/O1)
/USB_D-: U1.44 (PA11), U5.3 (I/O2)
/VBAT: C15.1, C33.2, D1.1 (A1), J1.1, J5.2, R61.2, TP1.1 (1_1), U4.3 (VIN)
/VBAT/ADC: C57.2, R61.1, R62.2, U1.8 (PC0)
GND: C3.1, C4.2, C5.2, C6.2, C7.2, C8.2, C9.2, C15.2, C16.1, C21.2, C22.1, C23.1, C24.2, C33.1, C34.2, C35.2, C36.2, C38.2, C46.2, C47.2, C48.2, C49.2, C50.2, C51.2, C52.2, C53.2, C54.2, C55.2, C56.2, C57.1, C58.1, C60.2, C62.2, C63.2, C64.2, C65.2, C68.2, C69.2, D1.2 (A2), J1.2, J1.MP (MountPin), J4.6 (VSS), J4.P1 (SHIELD), J4.P2 (SHIELD), J4.P3 (SHIELD), J4.P4 (SHIELD), J4.SWB (B), J5.1, J5.MP (MountPin), J7.4, J8.1, J8.MP (MountPin), J9.A1 (GND), J9.A12 (GND), J9.B1 (GND), J9.B12 (GND), J9.SH (SHIELD), J11.4, J11.MP (MountPin), J13.1, J13.MP (MountPin), LED1.3 (VSS), LED2.3 (VSS), LED3.3 (VSS), LED4.3 (VSS), Q1.2 (E), R1.1, R5.2, R14.1, R17.1, R62.1, Reset2.1, TP2.1 (1_1), TP6.1 (1_1), U1.12 (VSSA), U1.18 (VSS), U1.63 (VSS), U3.6 (GND_6), U3.9 (GND_9), U3.14 (GND_14), U3.20 (GND_20), U3.25 (GND_25), U3.30 (GND_30), U3.34 (GND_34), U3.39 (GND_39), U4.1 (GND), U5.2 (GND), U6.6 (GND), U7.1 (GND), U7.5 (SDO), U7.7 (GND), U9.2 (GND), U9.7 (GND), U10.2 (GND); also elsewhere on the board
unnamed: BZ1.2 (-), D4.2 (A), Q1.3 (C)
unnamed: C7.1, C9.1, D2.1 (K), D3.1 (K), U9.1 (EN), U9.3 (VIN), U10.1 (VIN), U10.3 (CE)
unnamed: J9.A5 (CC1), R14.2
unnamed: J9.B5 (CC2), R17.2
unnamed: Q1.1 (B), R6.2
unnamed: C3.2, U1.31 (VCAP_1)
unnamed: C4.1, U1.47 (VCAP_2)
unnamed: C14.1, U4.6 (BOOT)
unnamed: R4.1, R5.1, U4.4 (FB)
unnamed: C14.2, L1.1, U4.2 (SW)
unnamed: C38.1, U9.6 (BYP)

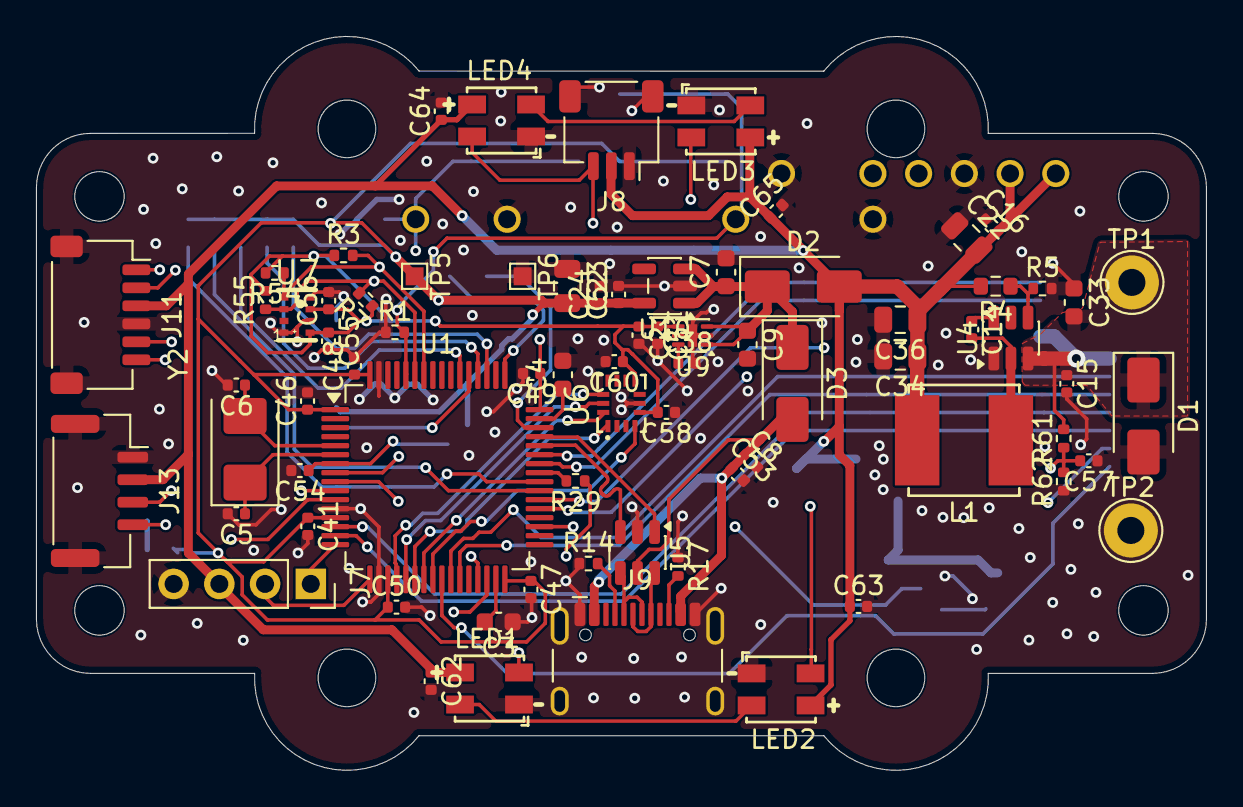
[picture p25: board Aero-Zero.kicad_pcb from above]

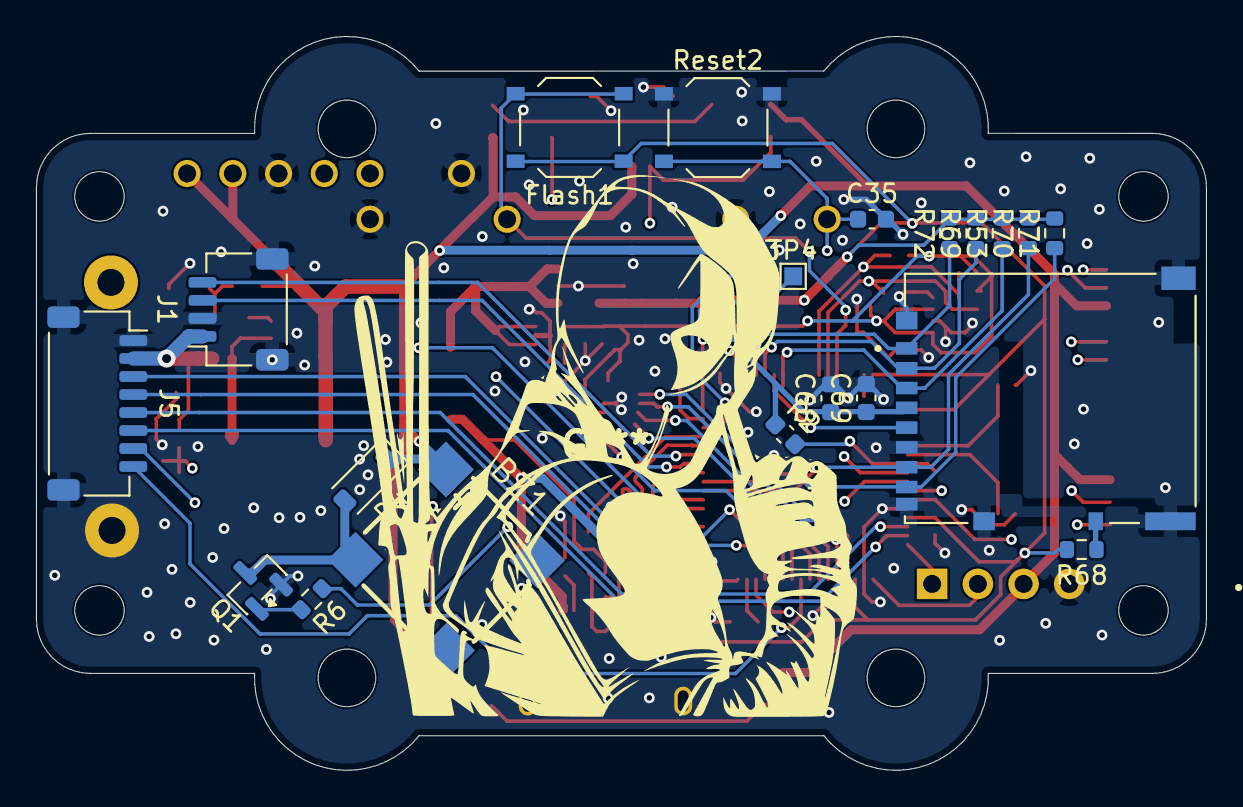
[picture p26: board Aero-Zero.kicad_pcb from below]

Board: 4 copper layers, 65.0 x 40.8 mm, 96 parts (21 on the bottom side), 65 nets.

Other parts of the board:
C41: 100nF; C_0402_1005Metric
R54, R55: 2,2K; R_0402_1005Metric

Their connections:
/3V3_SENSOR: R54.2, R55.2; also elsewhere on the board
/+3V3: C41.1; also elsewhere on the board
/I2C1_SCL: R54.1; also elsewhere on the board
/I2C1_SDA: R55.1; also elsewhere on the board
GND: C41.2; also elsewhere on the board

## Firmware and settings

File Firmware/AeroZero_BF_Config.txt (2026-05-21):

#first just open the folder CLI in Betaflight configurator and then just copy paste this text file into the cmd and press enter when finished


resource MOTOR 1 B00
resource MOTOR 2 B01
resource MOTOR 3 A00
resource MOTOR 4 A01
resource SPI_SCK 1 A05
resource SPI_MISO 1 A06
resource SPI_MOSI 1 A07
resource GYRO_CS 1 A04
resource GYRO_EXTI 1 C04
resource I2C_SCL 1 B06
resource I2C_SDA 1 B07
resource SERIAL_TX 1 A09
resource SERIAL_RX 1 A10
resource SERIAL_TX 2 A02
resource SERIAL_RX 2 A03
resource SERIAL_TX 3 B10
resource SERIAL_RX 3 B11
resource SERIAL_TX 6 C06
resource SERIAL_RX 6 C07
resource SERIAL_TX 5 C02
resource SERIAL_RX 5 C03
resource SERIAL_RX 4 C05
resource ADC_BATT 1 C00
resource ADC_CURR 1 C01
set sdcard_mode = SDIO
set blackbox_device = SDCARD
resource BEEPER 1 B14
resource LED 1 A08
set gyro_1_bustype = SPI
set gyro_1_spibus = 1
set gyro_1_sensor_align = CW0
set baro_bustype = I2C
set baro_i2c_device = 1
save

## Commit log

2026-05-21 Expand README with project details and BOM
    Added detailed project description, features, gallery, and bill of materials for the Aero-Zero Custom Flight Controller.
2026-05-21 Change PCB render images from JPG to PNG
    Updated image file extensions from .jpg to .png for 3D PCB renders.
2026-05-21 Rename Snímek obrazovky 2026-05-21 143457.png to schematics.png
2026-05-21 Rename Snímek obrazovky 2026-05-21 143509.png to pcb_b.png
2026-05-21 Rename Snímek obrazovky 2026-05-21 143522.png to pcb_in1.png
2026-05-21 Rename Snímek obrazovky 2026-05-21 143519.png to pcb_f.png
2026-05-21 Rename Snímek obrazovky 2026-05-21 143514.png to pcb_in2.png
2026-05-21 Add PCB and Schematics sections with images
2026-05-21 Rename Snímek obrazovky 2026-05-21 143424.png to schematics2.png
2026-05-21 Replace Fusion 360 Assembly images in README
    Updated images in the Mechanical Integration section.
2026-05-21 Update Fusion 360 assembly image in README
2026-05-21 Remove PCB images placeholder text
    Removed placeholder text for PCB images.
2026-05-21 Add price for Custom PCBA in Bill of Materials
    Added price for Custom PCBA (Aero-Zero) in the BOM.
2026-06-14 Fix image filename case for schematics
    Updated image filename for schematics to match case sensitivity.
2026-06-14 Revise microcontroller and BOM details in README
    Updated microcontroller and IMU details in the project features section. Adjusted prices and added new components in the Bill of Materials.
2026-08-02 Enhance Mechanical Integration section in README
    Added new section for CUSTOM AERO-ZERO CAD with images.
